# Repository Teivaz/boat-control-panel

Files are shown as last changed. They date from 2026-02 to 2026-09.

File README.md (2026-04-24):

# Panel 01

Electrical control panel for a boat. A single three-board unit that drives the
cabin relays, exposes them through a button panel with per-button RGB
feedback, and displays system state (battery, fuel and fresh-water level,
sensors, clock, nav-light selection) on a small OLED.

## Hardware layout

Three PIC18F27Q84 boards communicate over a shared I2C bus (multi-master):

| Board | Directory | Role |
|---|---|---|
| Switching | `circuit/board1-switching/` | 16 relay outputs (shift-register + mux back-read), 2 float-meter inputs, battery divider, 3 digital sensors (bilge / shore / AC). |
| Button (L/R) | `circuit/board2-buttons/` | 7 momentary buttons with per-button RGB indicator LEDs and configurable trigger modes. Two physical boards per unit (left and right), address selected by strap. |
| Main | `circuit/board3-main/` | SSD1322 OLED, DS3231 RTC, config switch. Orchestrates the other boards: receives button events, maintains relay intent, drives nav-light logic, and hosts the config menu. |

## Repository layout

- `firmware/` — C firmware for all three boards. Self-contained build via
  Docker (`firmware/build.sh`). See [`firmware/CLAUDE.md`](firmware/CLAUDE.md)
  and [`firmware/protocol.md`](firmware/protocol.md) for the I2C protocol,
  module conventions, and per-board details.
- `circuit/` — KiCad schematics and PCB layouts, one directory per board plus
  a shared symbol/footprint library (`panel-library.*`) and connection
  diagrams.
- `design/` — Front-panel artwork (Affinity Designer / Photo sources) and DXF
  exports for panel cutouts.
- `models/` — STEP files for mechanical assemblies and 3D-printed parts.
- `playground/` — Experimental sketches (currently the SSD1322 I2C display
  bring-up).

## Functional overview

- **Power**: a panel-wide power button on the left board gates every
  non-nav-light relay. Relay and nav-mode state are restored from a RAM
  snapshot when power is toggled back on.
- **Relays (5..15)**: instruments, autopilot, inverter, water pump, fridge,
  deck/cabin lights, USB, two aux channels. Each is tied to a single button
  and toggles on press. A button flags ERROR when the physical relay state
  doesn't converge to the requested one.
- **Nav lights (relays 0..4)**: anchoring / tricolor / steaming / bow / stern
  driven by a 3-button nav-mode selector. The main board filters requested
  combinations against the configured "enabled lights" mask (set in the
  config menu) and surfaces an error if the request is incompatible.
- **Config mode**: toggling the RA7 switch on the main board enters a menu
  (nav-light mask, time-of-day, water/fuel float offsets). The same buttons
  become menu navigation while active.
- **Button trigger modes**: each button has an independent trigger
  (release / hold / change) and time threshold, configured via the protocol
  and persisted to each board's data EEPROM.

## Firmware highlights

- No RTOS — all boards share a cooperative 1 ms-tick scheduler (`libcomm/
  task.c`) with a deferred ISR-to-main-loop queue (`run_in_main_loop`).
- Transport-agnostic protocol library (`libcomm/`) linked into all three
  boards. I2C, buttons, relays, NVM, and display code are board-local.
- Built with Microchip XC8 v3.10 inside a pinned Docker image; no MPLAB X
  install required. `./firmware/build.sh` from a board source directory
  produces a `.hex` in `dist/default/production/`.
- No unit tests — validation is done on hardware via a PICkit/ICD
  programmer. Per-board readmes in `firmware/board{1,3}/readme.md` document
  pinout and wiring.

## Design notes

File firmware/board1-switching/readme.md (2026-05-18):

#Board 1. Switching

This board contains 16 relay channels, each is controlled and monitored.

## Communication

RC3 SCK
RC4 SDA

## Relay controls

The relays are controlled with 2 shift registers MC74HC595A connected in series.

The "Address" column is the bit position in the 16-bit shift word, with bit 0
the lowest bit (transmitted last, lands at the near-end shift-register output).

| Protocol Bit | Address | Channel Name |
|---|---|---|
| 0 | 1 | main |
| 1 | 0 | instruments |
| 2 | 2 | autopilot |
| 3 | 3 | bow_light |
| 4 | 4 | stern_light |
| 5 | 5 | steaming_light |
| 6 | 6 | anchor_light |
| 7 | 8 | tricolor_light |
| 8 | 11 | inverter |
| 9 | 9 | fresh_water_pump |
| 10 | 10 | fridge |
| 11 | 14 | deck_lights |
| 12 | 7 | cabin_lights |
| 13 | 15 | usb |
| 14 | 12 | aux1 |
| 15 | 13 | aux2 |

### Pinout

RA0 A
RA1 LATCH_CLK
RA2 SHIFT_CLK
RB1 nRST

The nOUT_EN is connected to GND.

## Relay channel monitoring

The relay channel output is monitored via 2 multiplexer/demultiplexer SN74LV4051A connected in parallel.
Logical 1 on the input means the channel has power.

| Bit | Multiplexer | Channel Name |
|---|---|---|
| 5 | 0 | main |
| 2 | 1 | instruments |
| 7 | 0 | autopilot |
| 6 | 0 | bow_light |
| 4 | 0 | stern_light |
| 3 | 0 | steaming_light |
| 0 | 0 | anchor_light |
| 1 | 0 | tricolor_light |
| 7 | 1 | inverter |
| 2 | 0 | fresh_water_pump |
| 5 | 1 | fridge |
| 3 | 1 | deck_lights |
| 1 | 1 | cabin_lights |
| 0 | 1 | usb |
| 6 | 1 | aux1 |
| 4 | 1 | aux2 |

The addressing of the multiplexer is done with A B and C pins, simultaneous for both multiplexers. Reading done through COM pin. The nINH is connected to GND.

### Pinout

RB3 0A 1A
RB4 0B 1B
RB5 0C 1C
RA3 0COM
RA4 1COM

## Level sensors

The fresh water tank and fuel tank levels are measured by voltage on corresponding pins. The voltage is generated by current source and is correlated lineary with the resistance of the floats. Float can function in 0-190 Ω or 240–33 Ω. Current source is fixed at 5mA. The resistance of the wire should be taken into account when converting voltage to tank level (an offset value stored in EEPROM config).

Battery voltage is divided by 10 and sent to ADC input on the controller. Battery is a 12V acid. The voltage can be correlated with its charge via formula or lookup table.

### Pinout

RA7 Fuel tank level
RA5 Fresh water tank level
RA6 Battery voltage

## Other sensors

Additionally the chip is monitoring 3 on/off channels. High or low level on the pins indicates channel state.

RC1 Bilge float triggered
RC2 Shore power present
RC5 AC power present

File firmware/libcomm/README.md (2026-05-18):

# libcomm — Shared I2C Protocol Library

Shared library for multi-board I2C communication on PIC18F27/47/57Q84.

## Components

| File | Description |
|---|---|
| `i2c.h` / `i2c.c` | Async, interrupt-driven I2C multi-master driver (host + client) |
| `libcomm.h` / `libcomm.c` | Protocol message builders, parsers, and type definitions |
| `libcomm_interface.h` / `libcomm_interface.c` | High-level send/dispatch layer over I2C + libcomm |
| `task.h` / `task.c` | Cooperative task scheduler with ISR-safe deferred callbacks |

## I2C Driver (`i2c.h`)

Interrupt-driven I2C host + client driver on I2C1.  Default 100 kHz (400 kHz
when `I2C_FME=1`), 7-bit addressing, multi-master with automatic collision
retry.  Bus timeout uses the peripheral BTO (LFINTOSC).

No pin setup, no ISR definitions — boards provide pin/PPS in `i2c_board.c`;
ISRs are defined internally in `i2c.c`.

### API

```c
void i2c_init(uint8_t client_addr);     /* 0 = host-only                */
void i2c_set_cold_rx_handler(I2cCompletion); /* cold-rx delivery (main) */
I2cResult i2c_set_client_tx(uint8_t* tx, uint8_t tx_len); /* stage read reply */
I2cResult i2c_submit(addr, tx, tx_len, rx_len, cb, ctx);
void i2c_poll(void);                     /* main loop — fires callbacks  */
```

ISR-level functions (`I2C1_ISR`, `I2C1_ERROR_ISR`) are defined internally
in `i2c.c` — boards do not need to wire them manually.

### How it works

```
    Main loop                       ISR context
    ─────────                       ───────────

  i2c_submit() ──────┐
                     ▼
              ┌────────────┐
              │ Pending Q  │  ring buffer, 16 slots
              │ [0] [1]... │  each with 8-byte TX buffer
              └─────┬──────┘
                    │  i2c_poll()
                    ▼
              ┌────────────┐
              │ Active op  │  owns the I2C bus
              │ byte-level │  ISR shifts TX/RX per byte
              └─────┬──────┘
                    │  I2C1_ISR()     sets status flags
                    │  (BTO timeout)  enforces timeout
                    ▼
              ┌────────────┐
              │ Completed  │  i2c_poll() fires callback
              └────────────┘  and starts next queued op
```

### Context separation

| Function | Context | Notes |
|---|---|---|
| `i2c_init` | Main | Call once before super-loop |
| `i2c_set_cold_rx_handler` | Main | Set cold-rx delivery handler |
| `i2c_set_client_tx` | Main | Stage client read-reply buffer |
| `i2c_submit` | Main | Copies tx into queue, returns immediately |
| `i2c_poll` | Main | Fires callbacks, starts next op |

ISRs (`I2C1_ISR`, `I2C1_ERROR_ISR`) are internal to `i2c.c`.
No function is called from both contexts.

### Configuration

Override before including `i2c.h`:

| Define | Default | Description |
|---|---|---|
| `I2C_QUEUE_SIZE` | 16 | Queue depth (must be power of 2) |
| `I2C_TX_MAX` | 8 | Max bytes per TX payload |
| `I2C_RX_MAX` | 8 | Max bytes per RX payload |
| `I2C_CLIENT_BUF_SIZE` | 8 | Max inbound message size (client mode) |
| `I2C_RETRY_COUNT` | 1 | Retry count on bus collision / timeout |

### Board integration

```c
// In main.c:
i2c_pins_init();                  // board-specific pin setup (i2c_board.c)
i2c_init(comm_address());         // 0 = host-only
comm_interface_init();            // registers protocol dispatchers

// Main loop:
while (1) {
    i2c_poll();
    task_controller_poll(&ctrl);
}
```

ISRs are defined inside `libcomm/i2c.c` — boards do not need to provide them.

## Protocol Interface (`libcomm_interface.h`)

High-level layer that connects the I2C driver with the protocol
builders/parsers.  Provides:

1. **Send functions** — `comm_send_*()` for every protocol command
2. **Dispatchers** — automatically parse incoming I2C messages and
   call typed adopter callbacks
3. **Adopter callbacks** — board implements `comm_on_*()` for the
   commands it handles; empty stubs for the rest

### Outbound

```c
// Write commands (fire-and-forget):
comm_send_button_changed(button_id, pressed, mode, cb, ctx); // → main board
comm_send_relay_state(relays, cb, ctx);                       // → switching board
comm_send_button_effect(addr, &effect, cb, ctx);              // → button board

// Read commands (async response via callback):
comm_send_battery_read();     // response → comm_on_battery_read_response()
comm_send_config_read(addr, config_addr);
```

### Inbound (adopter implements)

```c
// Main-loop context — incoming writes:
void comm_on_button_changed_received(const CommButtonChanged* event);
void comm_on_channel_changed_received(const CommChannelChanged* event);
void comm_on_reset(void);

// Main-loop context — read responses:
void comm_on_battery_read_response(CommBattery* battery);

// ISR context — incoming read requests:
void comm_on_config_read_requested(uint8_t address);
```

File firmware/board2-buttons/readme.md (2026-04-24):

# The Board 2. Buttons

This board holds up to 8 buttons with corresponding RGB LEDs for feedback.

The buttons are connected to a port directly and on press shorten the pin to GND.
The RGB LEDs are connected in series from 0 to 7. With 7 not installed.

## Pinout

RA5 Button 0
RA4 Button 1
RA3 Button 2
RA2 Button 3
RA1 Button 4
RA0 Button 5
RA6 Button 6
RA7 Button 7 (not connected)

RC2 RGB LED

RC3 SCL
RC4 SDA

RB0 L/R
RB1 Reserved

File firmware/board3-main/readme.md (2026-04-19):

# Board 3. Main

The main board keeps track of all internal states, it receives messages from other boards (e.g. buttons) or polls (~200ms) boards (e.g. RTC). This board also is equipped with 64x256 display where in the normal mode it only shows 3 items: level of fresh water, level of fuel, charge of the battery (acid 12V battery, measured by voltage). This board controls navigational lights (bow, stern, steaming, anchoring, tricolor).

## Communications

RB1 SDA
RB2 SCL

Other
RA7 CONFIG_MODE (changes the main board mode into configuration disabling normal functionality)

## Navigational lights

The board also shows the state of each navigational light. This state corresponds to the state of the corresponding channel on the switching board.
The lights are connected in the followign order:

- Anchoring
- Tricolor
- Steaming
- Bow
- Stern

The lights operate in following modes:

- Off
- Anchoring. Combination of anchoring or steaming+stern.
- Steaming. Combination of stern+bow+steaming or bow+anchoring.
- Running. Combintation of stern+bow or just tricolor.

In the config mode any light can be disabled. The system then should find a way to implement the required light pattern using available lights. If not possible it should flash red to indicate error.

The leds used LTST-E563C.

### Pinout

RB5 LED (series of 5)

## Buttons

Communication with buttons is done throught I2C specified in protocol.md.

Left button panel has buttons connected in following order:

- Power. Toggles the functionality of the whole pannel. When off none of the relays are activated.
- Instruments. Controls instruments relay.
- Autopilot. Controls autopilot relay.
- Steaming lights. Enables Steaming mode of navigational lights. When mode is already active it switches the mode to Off. Contols some of the navigational lights relays.
- Runnning lights. Enables Running mode of navigational lights. When mode is already active it switches the mode to Off. Contols some of the navigational lights relays.
- Anchoring lights. Enables Anchoring mode of navigational lights. When mode is already active it switches the mode to Off. Contols some of the navigational lights relays.
- Inverter. Controls inverter relay.

Left button panel has buttons connected in following order:

- Fresh water pump.
- Fridge.
- Deck lights.
- Cabin lights.
- USB outlets.
- Aux 1.
- Aux 2.

The button once pressed should be put into pulsating mode, then trigger corresponding channel on the switching board. Once the channel status on the switching board is set the button effect should be changed to enabled.
If the button state is not changed after 100ms the channel state should be changed to error, which should be displayed as red flashing light. Toggling the button again should clear error state and turn the channel off.

## Relays

Communication with relays is done throught I2C specified in protocol.md.

## Display

The display is SSD1322 OLED monochrome display 64x256 operating in 8080 mode. nCS connected permanently to GND, EnRD pulled up.

The graphics library u8g2, the parts of the library that are used need to be copied to the source folder.

### Pinout

RB0 DnC
RB3 nRST
RB4 RnW
RC0 D0
RC1 D1
RC2 D2
RC3 D3
RC4 D4
RC5 D5
RC6 D6
RC7 D7

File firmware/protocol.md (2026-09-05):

# I2C Communication Protocol Description

All devices should be able to operate in standard (100 kHz) and fast (400 kHz) modes.
The system operates in multi-master mode with an event-based system. If a device needs to implement polling the time interval for polling calls should be ≥ 20 ms.
Addressing scheme is 7-bit.
Signal lines are pulled up to 3.3V.

## Addresses

0x40 - Main control board
0x41 - reserved
0x42 - Switching board
0x43 - reserved
0x44 - button board L
0x45 - button board L2
0x46 - button board R
0x47 - button board R2
0x48..0x4F - reserved
0x68 - RTC module (DS3231)

## Messages

All write messages begin with a command byte (byte 0) with the MSB clear (0x00–0x7F). Read messages use a write phase to send the command byte with the MSB set (0x80–0xFF), followed by a repeated-start read phase. The read command ID equals the write command ID OR 0x80.

### Checksum

Every on-wire message ends with a single CRC-8 byte (polynomial `0x07`, initial value `0x00`, no final XOR — the SMBus/SAE-J1850 CRC). The CRC is computed over every preceding byte of that message:

- **Write messages** (id + payload): CRC spans `[id, payload[0..N-1]]`. Total wire length is `1 + N + 1` bytes.
- **Read-phase responses** (payload only, no id): CRC spans `[payload[0..N-1]]`. Total wire length is `N + 1` bytes.
- **Command-only messages** (`reset`, most `*_read` write phases): CRC spans `[id]` alone. Total wire length is 2 bytes.

Receivers drop any message whose trailing byte doesn't match the computed CRC. Per-byte payload sizes below do **not** include the CRC byte; add 1 to the byte count on the wire.

| Command | Value | Direction |
| --- | --- | --- |
| `reset` | 0x0F | main → any (write) |
| `config` | 0x0E | main → any (write) |
| `config_read` | 0x8E | main → any (read) |
| `button_effect` | 0x01 | main → button board |
| `button_changed` | 0x02 | button board → main |
| `button_state_read` | 0x83 | main → button board (read) |
| `button_trigger` | 0x04 | main → button board (write) |
| `button_trigger_read` | 0x84 | main → button board (read) |
| `relay_state` | 0x05 | main → switching board (write) |
| `relay_state_read` | 0x85 | main → switching board (read) |
| `channel_changed` | 0x06 | switching board → main |
| `channel_state_read` | 0x87 | main → switching board (read) |
| `battery_read` | 0x88 | main → switching board (read) |
| `levels_read` | 0x89 | main → switching board (read) |
| `level_mode` | 0x0A | main → switching board (write) |
| `level_mode_read` | 0x8A | main → switching board (read) |
| `sensors_read` | 0x8B | main → switching board (read) |
| `test_echo` | 0x0C | any → any (write) |
| `test_echo_response` | 0x0D | any → requester (write) |
| `test_read` | 0x8C | any → any (read) |

### Common

The following commands are supported by every addressable device.

- reset - perform a soft reset; the device restarts as if powered on. No response is emitted.
  - write byte 0: command - 0x0F

- config - write one byte of the device configuration. Persisted to non-volatile storage; survives power cycles. Address space and byte meaning are device-specific.
  - write byte 0: command - 0x0E
  - write byte 1: address - byte offset within the device configuration
  - write byte 2: value - configuration byte to store

- config_read - read one byte of the device configuration
  - write byte 0: command - 0x8E
  - write byte 1: address - byte offset within the device configuration
  - read byte 0: value - configuration byte at the requested address

The low end of the configuration address space is reserved for universal fields present on every device. Device-specific fields live at `0x10` and above.

| Address | Field | Access | Description |
|---|---|---|---|
| 0x00 | device_id | read-only | 7-bit I2C address of this device; matches the address used to reach it |
| 0x01 | hw_revision | read-only | Hardware revision, monotonic per board |
| 0x02 | sw_revision | read-only | Firmware revision, monotonic per build |

#### Diagnostic test commands

Bus-bring-up / integration-test helpers. Every device services them with no application involvement.

- test_echo - the requester writes its own address and an arbitrary value; the receiver replies with a `test_echo_response` write addressed to that requester, carrying the responder's own address and the same value. The `address` field always identifies the sender, so the requester learns which device answered. Exercises the multi-master write path in both directions (requester and receiver must each act as host).
  - write byte 0: command - 0x0C
  - write byte 1: address - requester's own I2C address (where the response is sent)
  - write byte 2: value - arbitrary value, echoed back unchanged

- test_echo_response - the reply emitted by a device that received a `test_echo`.
  - write byte 0: command - 0x0D
  - write byte 1: address - responder's own I2C address
  - write byte 2: value - the value from the test_echo, unchanged

- test_read - the write phase carries one value byte; the read phase returns that same byte. Exercises the client-TX read-staging path with a single host (no second master needed).
  - write byte 0: command - 0x8C
  - write byte 1: value - arbitrary value to be echoed
  - read byte 0: value - the value from the write phase, unchanged

### Main board (0x40)

- button_changed - pushed by a button board when a button's trigger fires, or when its trigger is (re)configured
  - write byte 0: command - 0x02
  - write byte 1: device_address - address of the sending button board
  - write byte 2: button_id - `[7:6]` = 0, `[5:4]` = button mode, `[3]` button pressed, `[2:0]` button index

- channel_changed - pushed by the switching board when any channel-voltage bit (mux-observed downstream of each relay's fuse) or any sensor changes state
  - write byte 0: command - 0x06
  - write byte 1: device_address - address of the sending switching board
  - write byte 2: prev_channels_lo - previous channel-voltage state of channels 0–7; bit N = channel N
  - write byte 3: prev_channels_hi - previous channel-voltage state of channels 8–15; bit N = channel N−8
  - write byte 4: current_channels_lo - current channel-voltage state of channels 0–7
  - write byte 5: current_channels_hi - current channel-voltage state of channels 8–15
  - write byte 6: prev_sensors - previous sensor state; `[7:3]` = 0, `[2]` sensor_2, `[1]` sensor_1, `[0]` sensor_0
  - write byte 7: current_sensors - current sensor state; same layout as prev_sensors

### Button board (0x44–0x47)

The input register is 1 byte representing the physical state of 8 buttons (bit N = button N; 1 = pressed, 0 = released). The trigger mode determines when a `button_changed` is emitted per button, but the register value always reflects the raw button state.

Each button has an independent mode and timing configured via `button_trigger`:

| Mode | Bits | Behaviour |
|---|---|---|
| `unknown` | `00` | No trigger configured; no events fire. Default on power-on. |
| `release` | `01` | Event fires when the button is released after being held for ≥ the configured time. No event if released early. |
| `hold` | `10` | Event fires once when the button has been held for ≥ the configured time. |
| `change`  | `11` | Event fires on every button state change. No time parameter. |

- button_effect - set the visual effect for each of the 8 button outputs
  - write byte 0: command - 0x01
  - write byte 1: outputs_76 - upper nibble = output 7, lower nibble = output 6
  - write byte 2: outputs_54 - upper nibble = output 5, lower nibble = output 4
  - write byte 3: outputs_32 - upper nibble = output 3, lower nibble = output 2
  - write byte 4: outputs_10 - upper nibble = output 1, lower nibble = output 0

  Each nibble encodes one output as `CC MM` — `[3:2]` color, `[1:0]` mode.

  | CC | Color |
  |---|---|
  | 00 | white |
  | 01 | red |
  | 10 | green |
  | 11 | blue |

  | MM | Mode |
  |---|---|
  | 00 | disabled |
  | 01 | enabled |
  | 10 | flashing (fast) |
  | 11 | pulsating (slow) |

- button_state_read - polled read; returns the current physical state of all buttons
  - write byte 0: command - 0x83
  - read byte 0: current_state - current value of the input register

- button_trigger - write the trigger configuration for a single button
  - write byte 0: command - 0x04
  - write byte 1: `[7:3]` = 0, `[2:0]` button_id
  - write byte 2: `MM EE TTTT` — mode and timing for the button

  Default value on power-on is `0x00` (`unknown`, no events).

  **Time encoding:** `t = TTTT × 10^EE ms`. TTTT=0 means immediate (t=0ms).

  | EE | Resolution | Range |
  |---|---|---|
  | 0 | 1 ms | 1–15 ms |
  | 1 | 10 ms | 10–150 ms |
  | 2 | 100 ms | 100–1500 ms |
  | 3 | 1000 ms | 1–15 s |

- button_trigger_read - read the trigger configuration for a single button
  - write byte 0: command - 0x84
  - write byte 1: `[7:3]` = 0, `[2:0]` button_id
  - read byte 0: `MM EE TTTT` for the requested button

### Switching board (0x42)

The switching board has 16 relay channels. Each channel has three observable states:

- **relay target** — what the firmware was last commanded to set (`relay_state` write).
- **channel voltage** — the voltage observed downstream of the relay's fuse, read via the relay-output mux. A blown fuse can leave a relay commanded ON while its channel reads 0; a stuck contactor can do the inverse.

Both states are 2-byte bitmasks transmitted low byte first: byte 0 = bits 0–7, byte 1 = bits 8–15 (bit N = channel N; 1 = on, 0 = off).

- relay_state - write the target state of all 16 relays
  - write byte 0: command - 0x05
  - write byte 1: relays_lo - target state of relays 0–7
  - write byte 2: relays_hi - target state of relays 8–15

- relay_state_read - read the commanded target state of all 16 relays (the last value written via `relay_state`)
  - write byte 0: command - 0x85
  - read byte 0: relays_lo
  - read byte 1: relays_hi

- channel_state_read - read the channel-voltage state of all 16 channels (mux-observed; reflects fuse / contactor health, not just the commanded relay target)
  - write byte 0: command - 0x87
  - read byte 0: channels_lo
  - read byte 1: channels_hi

- battery_read - polled read; returns battery voltage as an unsigned 16-bit value
  - write byte 0: command - 0x88
  - read byte 0: voltage_lo - low byte
  - read byte 1: voltage_hi - high byte

- levels_read - polled read; returns both level meter values in a single message
  - write byte 0: command - 0x89
  - read byte 0: level_0 - unsigned 8-bit value of level meter 0
  - read byte 1: level_1 - unsigned 8-bit value of level meter 1

- level_mode - write the operating mode of both level meters
  - write byte 0: command - 0x0A
  - write byte 1: `[7:4]` = 0, `[3:2]` mode_1, `[1:0]` mode_0

  Mode values (matching `CommMeterMode` in `libcomm.h` — the wire encoding is
  the enum value, so these must stay in lockstep):

  | Value | Name | Meaning |
  |---|---|---|
  | `00` | `COMM_METER_MODE_CALIBRATION` | Raw Ω passthrough — the reported byte is the calibrated resistance, not a percentage. Selected via the main board's config menu (water/fuel mode items) so the operator can watch the sender's actual resistance while picking the matching `water_cal` / `fuel_cal` byte. |
  | `01` | `COMM_METER_MODE_0_190` | European, 0–190 Ω; full = high resistance. **Default.** |
  | `10` | `COMM_METER_MODE_240_33` | American, 240–33 Ω; full = low resistance. |
  | `11` | — | Reserved. |

  A resistance more than 1.5× beyond the mode's high-resistance end (>360 Ω in
  `0b10`, >285 Ω in `0b01`) is reported as the over-range sentinel 255 — float
  disconnected or sender rail open — which the main board renders as an error
  rather than a level. In `COMM_METER_MODE_CALIBRATION` there is no sentinel:
  the byte is the raw Ω value clamped to 255, so 255 there means "≥255 Ω".

- level_mode_read - read the operating mode of both level meters
  - write byte 0: command - 0x8A
  - read byte 0: `[7:4]` = 0, `[3:2]` mode_1, `[1:0]` mode_0

- sensors_read - polled read; returns the state of all 3 on/off sensors
  - write byte 0: command - 0x8B
  - read byte 0: `[7:3]` = 0, `[2]` sensor_2, `[1]` sensor_1, `[0]` sensor_0 — 1 = on, 0 = off

## Configuration

Configuration is per-device byte-addressable storage backed by data EEPROM. `config` writes are persisted across power cycles; `config_read` returns the in-RAM shadow that mirrors EEPROM. A byte that has never been written reads back as 0xFF (the EEPROM erase pattern); accessors with a sensible fallback substitute the per-field default listed below.

Universal addresses 0x00..0x0F are documented in [Common](#common). Device-specific fields:

### Main board configuration (0x40)

| Address | Field | Size | Default | Description |
|---|---|---|---|---|
| 0x10 | nav_enabled_mask | 1 | 0x1F | 5-bit mask of physically-installed nav lights — `[0]` anchoring, `[1]` tricolor, `[2]` steaming, `[3]` bow, `[4]` stern. Limits which lights the panel attempts to drive when a nav-mode button is pressed; cleared bits are silently skipped and a mode that requires a missing light raises a config error on the indicator. |
| 0x11 | indicator_brightness | 1 | 0x10 | Peak per-channel intensity (0..255) for the nav-indicator RGB ring. Re-read each frame so a runtime change takes effect within ~50 ms. Kept in lockstep with the button board's `led_brightness` so the panel reads uniformly. |

### Button board configuration (0x44–0x47)

| Address | Field | Size | Default | Description |
|---|---|---|---|---|
| 0x10..0x16 | button_trigger[7] | 7 | hold trigger | One CommTriggerConfig (MMEETTTT) per button — same wire format as `button_trigger` command payload. Default mode is `hold` with a 1 ms time on most buttons; the L-board's button 0 defaults to 800 ms. |
| 0x17..0x1A | button_effect | 4 | disabled / white | Four packed CommButtonEffect bytes (two outputs per byte; upper nibble = odd output, lower nibble = even output) — same wire format as `button_effect` command payload. Default colour is white, mode disabled (LEDs dark). |
| 0x1B | led_brightness | 1 | 0x10 | Peak per-channel intensity (0..255) for the per-button RGB LEDs. Applied uniformly across R/G/B so hue is preserved; re-read each frame. Kept in lockstep with the main board's `indicator_brightness` so the panel reads uniformly. |

### Switching board configuration (0x42)

| Address | Field | Size | Default | Description |
|---|---|---|---|---|
| 0x10 | water_cal | 1 | 100 | Water-level scale factor — byte the channel reports with a 100 Ω reference applied. The ADC processor inverts the factor when displaying Ω so a tolerance-shifted current source / divider just changes this byte. |
| 0x11 | fuel_cal | 1 | 100 | Fuel-level scale factor — same calibration semantics as `water_cal`. |
| 0x12 | battery_cal | 1 | 120 | Battery scale factor — byte the channel reports at a 12000 mV reference, in 100 mV units. |
| 0x13 | level_mode | 1 | 0x05 | Packed CommLevelMode — `[3:2]` mode_1, `[1:0]` mode_0; same layout as `level_mode` command payload. Persists meter mode across reboot. Default 0x05 = both meters in 0–190 Ω mode (`COMM_METER_MODE_0_190` in both fields). |

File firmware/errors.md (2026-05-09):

# Compilation Warnings Audit

Snapshot of XC8 v3.10 and clang diagnostics across `board1-switching`,
`board2-buttons`, `board3-main` as of 2026-04-24. All three boards build
clean (no errors). Warnings are grouped by mechanism; each entry lists the
root cause and whether action is warranted.

## 1. Non-reentrant duplication for `run_in_main_loop` (resolved)

```
task.c:120: advisory (2098) indirect function call via a NULL pointer ignored
task.c:120: warning  (759)  expression generates no code
task.c:100..102: advisory (1498) pointer (run_in_main_loop@c) may have no targets
```

These warnings applied when no board called `run_in_main_loop`. Since then,
`board2-buttons/input.c:62` calls `run_in_main_loop(ctrl, dispatch_pending, 0)`
from its IOC ISR to defer button debounce into main context. With a live
caller the pointer analysis resolves and the dispatcher is emitted. These
warnings should no longer appear for board2-buttons builds.

## 2. Dead code in board modules (520 — never called)

Functions declared and defined in board-local modules with no caller in the
linked image. Linker drops them from the final hex; cost is source clutter.

### board3-main/controller.c
- `controller_power_on` (211)
- `controller_nav_mode` (214)
- `controller_relay_target` (220)
- `controller_sensors` (232)

Four getters that were likely intended for `comm.c` to serve read requests
but aren't wired. `board3-main/comm.c` has no callers for them.

### board2-buttons
- `config.c:131` `config_set_button` — wrapper over `config_write_byte`.
  The dispatcher in `comm.c:100` calls `button_set_trigger` directly
  instead, which internally persists.
- `config.c:146` `config_set_effect` — same pattern; dispatcher calls
  `led_effect_set` directly (`comm.c:156`).
- `led_effect.c:35` `led_effect_get` — no reader of current effect state.

**Action**: either delete the dead wrappers or route the dispatcher through
them (would consolidate persistence into `config.c`). Low priority.

## 3. Unused libcomm API per board (520)

`libcomm/libcomm.c` exports builders and parsers for every command in the
protocol. Each board links all of them but only calls a subset:

| Board | Unused command families (sample) |
|---|---|
| board1-switching | all button\_\* builders/parsers, button\_effect\_\*, config builders, relay\_mask\_\*, relay\_changed, reset, sensors\_read |
| board2-buttons | relay\_\*, battery, levels, level\_mode, sensors, config builders |
| board3-main | build\_button\_changed, button\_trigger\_\*, most read-side builders |

**Impact**: none — XC8 linker discards unreferenced symbols.

**Action**: none. This is inherent to sharing one library across
heterogeneous devices. Could be eliminated with per-board `-D` guards
around optional builders, but the added conditional compilation costs more
than the dead code.

## 4. Non-reentrant duplication (1510)

```
... non-reentrant function "_X" appears in multiple call graphs
    and has been duplicated by the compiler
```

Affected across all boards: any module whose API is reachable from both
main and ISR contexts — `config_read_byte`, `config_write_byte`,
`queue_lookup`, `eeprom_offset_for`, `nvm_read`, `i2c_*`, `sensors_state`,
`button_set_trigger`, `button_index`, `led_effect_set`, `input_state_current`,
`task_controller_add`, `task_controller_remove`, `find_slot`, `comm_address`,
and the XC8 runtime helpers (`__awdiv`, `__lwdiv`, `__lwmod`).

**Cause**: XC8's 8-bit model disallows reentrancy by default — locals sit
in fixed allocation banks rather than on a stack. When the same function
is reached from two call graphs (ISR + main), XC8 duplicates the code so
each context has its own locals. This is correct and is the mechanism that
makes our ISR-callable annotations safe.

**Impact**: modest code-size hit (one extra copy per duplicated function).
Already accounted for in the 7.8% / 10.0% program-space usage reported by
the build.

**Action**: none. Confirms the ISR-callable annotations accurately reflect
reality. If code space ever gets tight, candidates for ISR→defer rework
would reduce duplication.

## 5. Function-pointer targets unresolved (1498 advisory)

```
advisory: (1498) pointer (<fn>@<param>) in expression may have no targets
```

Fires for every libcomm builder/parser taking `CommMessage*` or typed
output pointers. XC8 cannot resolve the targets because the callers pass
`&local` from a different translation unit.

**Impact**: none — pure static-analysis limitation. The calls are
resolvable by ordinary C semantics at link time.

**Action**: none.

## 6. u8g2 vendor warnings (board3-main only)

Two groups, both from the vendored `u8g2/` subtree:

- **clang sign-conversion / int-conversion** (~100 hits across
  `u8g2_arc.c`, `u8g2_font.c`, `u8g2_polygon.c`, `u8g2_selection_list.c`,
  `u8g2_ll_hvline.c`, `u8g2_kerning.c`, `u8g2_message.c`,
  `u8g2_input_value.c`, `u8x8_cad.c`). Upstream style; not our code.
- **XC8 (1481) "call from non-reentrant function … to `_byte_cb` might
  corrupt parameters"** on the u8x8 display-driver dispatch pointers.
  `_byte_cb` is u8g2's callback registered from a single context, but XC8
  sees it reachable from multiple drivers and cannot prove reentrancy
  safety.

**Impact**: vendor code runs only from main context in our use, so the
(1481) parameter-corruption warning is spurious for our call pattern. The
clang sign warnings are cosmetic.

**Action**: none. Touching `u8g2/` would diverge from upstream.

## 7. Summary

- 1 resolved concern (§1) — `run_in_main_loop` now has a live caller in
  board2-buttons; warnings should no longer appear for that board.
- 7 locally dead functions (§2) — candidates for cleanup in a follow-up.
- Everything else (§3–§6) is structural: consequence of a shared library
  over heterogeneous devices, the XC8 non-reentrancy model, or vendor code.

Build output captured with `../build.sh` from each board directory after
`make clean CONF=default`.

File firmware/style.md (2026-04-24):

# Firmware style & consistency notes

Derived from a file-by-file audit of `board1-switching/` and `board2-buttons/`. These are the conventions the board already follows (and which `.clang-format` does not by itself capture), followed by the inconsistencies found during the audit and the fixes applied.

## Conventions in use

### Module layout
- One `foo.h` / `foo.c` pair per responsibility (`adc`, `i2c`, `relay_out`, `relay_mon`, `sensors`, `controller`, `config`, `comm`, `interrupt`).
- `foo_init(...)` is always the first exported symbol. Modules that schedule periodic work take `TaskController* ctrl` so the caller owns the scheduler; modules with no timed work take no argument (`adc_init`, `i2c_init`, `relay_out_init`, `relay_mon_init`, `comm_init`).
- Header comments describe *what the unit owns and how to call it*, not line-by-line behavior.

### Naming
- Exported functions: `module_verb[_noun]` (`relay_out_write`, `adc_read_battery_mv`, `controller_set_relay_target`, `sensors_state`).
- File-static helpers: verb-first, no module prefix (`apply_target`, `start_burst`, `handle_event`, `flush_task`, `ioc_handler`).
- Scheduled callbacks end in `_task` (`monitor_task`, `retry_task`, `flush_task`, `poll_task`).
- Task IDs live in each board's `task_ids.h` as an anonymous `enum`, `TASK_*` prefix.
- Pin/register aliases use `PIN_*` or `SEL_*` / `COM_*` macros (`PIN_NRST`, `SEL_A`, `PIN_BILGE`).
- Compile-time constants: `SCREAMING_SNAKE_CASE` with a module-specific prefix (`ADC_FVR_MV`, `SENSORS_POLL_MS`, `WRITE_QUEUE_SIZE`).

### Types & argument style
- `uint8_t` is the default integer. `uint16_t` for relay masks and raw ADC counts, `uint32_t` only where required (EMA accumulators).
- Pointer declarations use `Type* name` (matches `.clang-format`'s `PointerAlignment: Left`).
- Every no-arg function is declared as `func(void)` — including ISRs.
- Buffer parameters always come as `(const uint8_t* data, uint8_t len)` pairs; response buffers as `(uint8_t* response, uint8_t response_max)` with the return value being the number of bytes written.
- Status enums (`I2cResult`) are returned; scheduler-style functions return `int8_t` with documented negative codes.
- Bitfield struct fields keep the LSB-first layout that matches the wire format — never reorder.

### Concurrency discipline
- **Main context**: `main()`, `task_controller_poll`, every `*_task` callback.
- **ISR context**: each peripheral ISR (`I2C1_ISR`, `AD_ISR`, `IOC_ISR`, `TMR0_ISR`) plus the `on_rx` / `on_read` handlers that `i2c.c` invokes from its ISR. Every ISR-callable function carries an `ISR context` / `ISR-callable` comment.
- Any variable shared between the two is `volatile`. Multi-byte volatile reads/writes from main context wrap access in `INTERRUPT_PUSH` / `INTERRUPT_POP` (from `libcomm.h`). Pure-ISR shared variables don't need the guard because ISRs don't preempt each other here.
- ISR context → main context handoff uses a `push_dirty` flag plus a periodic task that drains the state; handlers invoked from an ISR (`on_rx`, `on_read`, change callbacks) must stay short and avoid blocking peripherals.

### Interrupts
- All vectors use `__interrupt(irq(NAME), base(8))` with the IVT locked at `0x0008` by `interrupt_init`.
- Each ISR is defined in the module that owns the peripheral it serves (`TMR0_ISR` in `main.c`, `IOC_ISR` in the input/sensors module that enables IOC, `I2C1_ISR` in `i2c.c`, `AD_ISR` in `adc.c`). The peripheral-specific interrupt enablement (`PIE*`, `IPR*`, and the peripheral's `IE`/`IP` bits) lives alongside the ISR in the same module.
- `interrupt.c` holds only `interrupt_init` (IVT lock/unlock + `GIE`) plus `__asm("RESET")` stubs for vectors that no module claims. No function-pointer dispatch table.

### Comments
- Top-of-file comment: what the module owns, how the hardware is wired, and any non-obvious invariants (e.g. the wire-bit ↔ protocol-bit mapping tables, EMA time constant rationale).
- Inline: only where the *why* is not obvious (register magic numbers, timing assumptions, mid-flight glitch handling).
- No running narration of what the next line does.

## Findings and fixes

### Fixed
1. **`controller_level` parameter name drift**
   Header declared `controller_level(uint8_t meter_index)` but the definition used `uint8_t i`. Renamed to `meter_index` to match.

2. **Dead accessor `controller_relay_physical`**
   Declared in `controller.h` and defined in `controller.c`, never called. `relay_physical` is still used internally by `monitor_task` / `retry_task`; only the unused getter and its declaration were removed.

3. **Stray-vector ISR signatures**
   `interrupt.c` declared every reset-trap ISR with an empty `()` argument list (e.g. `SWINT_ISR()`), while the two real handlers in the same file (`IOC_ISR(void)`, `TMR0_ISR(void)`) used `(void)`. All reset-trap ISRs now use `(void)` for consistency.

4. **Module-private state marked `extern`**
   `interrupt_handler_IOC` and `interrupt_handler_TMR0` were file-scope non-`static`, exposing them as global symbols even though only `interrupt.c` uses them. Marked `static`.

### Accepted as-is
- **`comm.c` `COMM_LEVEL_MODE` handling** skips `comm_parse_level_mode_write` and passes `data[1]` directly to `controller_set_level_mode`, which masks with `0x0F`. The parser itself just does the same `& 0x0F`, so the net effect is identical and routing a 1-byte bitfield through a parser-and-cast would be noisier than the current line. If more fields are added to `CommLevelMode` later, switch to the parser.
- **`adc_read_level_fresh_water` / `adc_read_level_fuel` duplication**. Two near-identical one-liners; per the "reuse after the third copy" rule this is still acceptable. Revisit if a third level meter appears.
- **clangd false positives** (`task.h`/`xc.h` not found, `GIE` undeclared). The Makefile supplies `-I../libcomm` and the XC8 DFP path at build time; standalone clangd doesn't see them. Not a source issue.

## For new code in this repo

- Mirror the `_init(TaskController*)` + `_task` pattern for anything that needs periodic work — don't add a second scheduling mechanism.
- Keep I2C-command dispatch in `comm.c`; keep transport (`i2c.c`) free of libcomm types.
- When a handler has to move data from ISR to main context, use a `volatile` shadow + dirty flag drained by a task — not a callback that blocks in the ISR.
- Wire a fresh IRQ by adding the `__interrupt(irq(...), base(8))` definition in the module that owns the peripheral and deleting the matching reset-trap stub in `interrupt.c`. Enable the interrupt (`PIE*`, `IPR*`) in the same module.

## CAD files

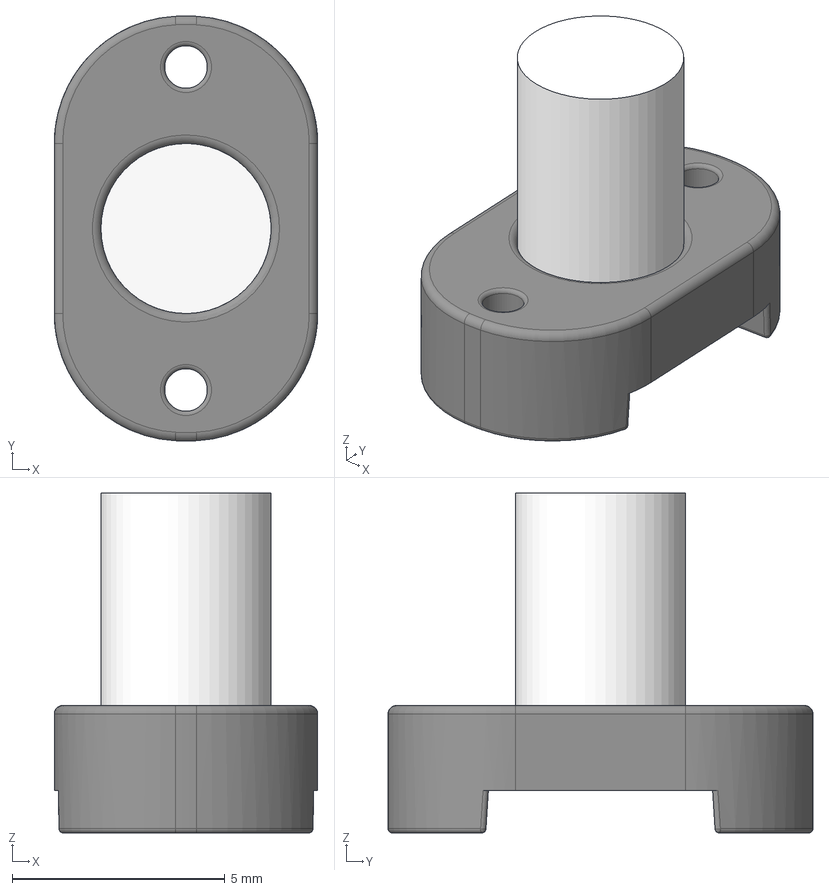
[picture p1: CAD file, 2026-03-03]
circuit/3dmodels/Ledpipe-5x5.step
6.20 x 10.00 x 8.00 mm

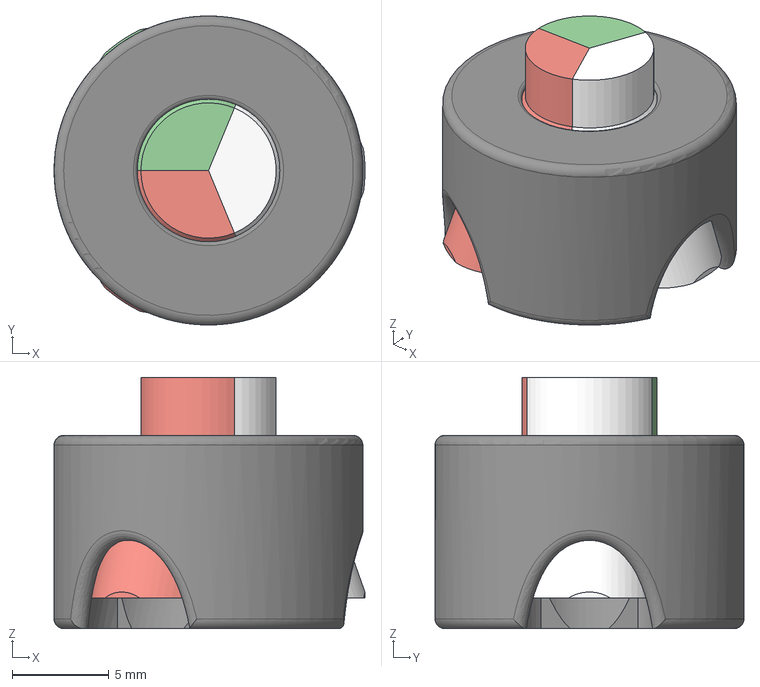
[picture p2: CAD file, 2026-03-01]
circuit/3dmodels/ledpipe_3p.step
16.1 x 16.0 x 13.0 mm

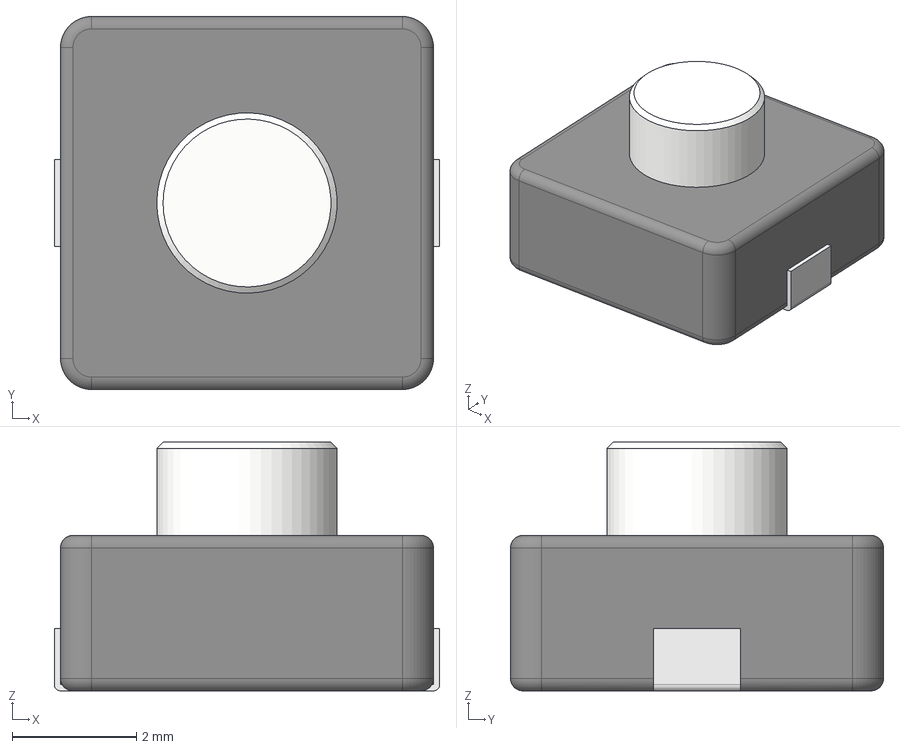
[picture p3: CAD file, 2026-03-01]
circuit/3dmodels/Button-EVPCD.step
6.20 x 6.00 x 4.00 mm

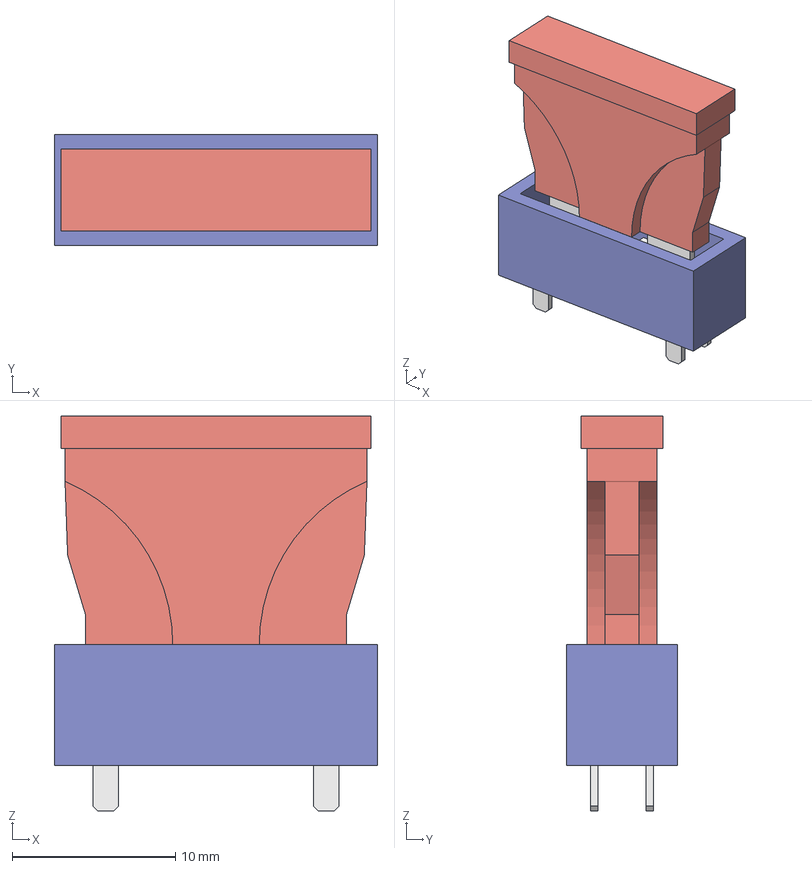
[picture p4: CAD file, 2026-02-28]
circuit/3dmodels/BladeFuseHolder.step
19.8 x 6.80 x 24.2 mm
BladeFuseHolder
BladeFuse

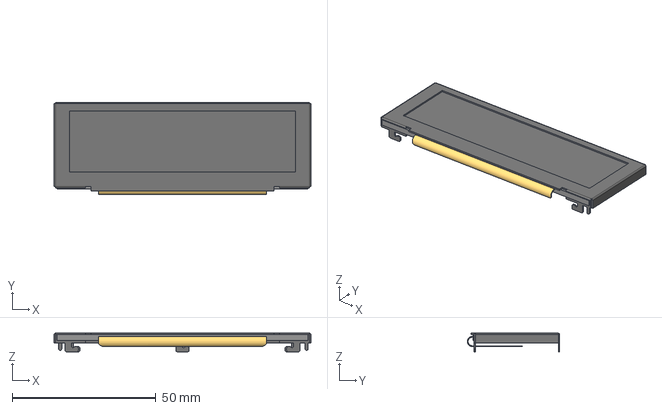
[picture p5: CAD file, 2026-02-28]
circuit/3dmodels/Display_OLED_3.12in.step
89.5 x 32.2 x 6.50 mm
Display_3.12in
Display_3.12in_frame

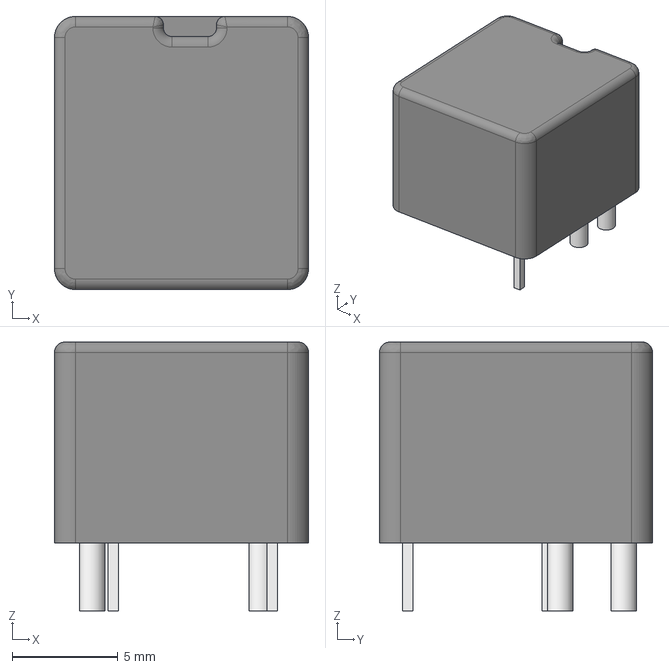
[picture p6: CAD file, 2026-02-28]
circuit/3dmodels/Relay-TE-V23086-C1xxx.step
12.0 x 12.9 x 12.7 mm

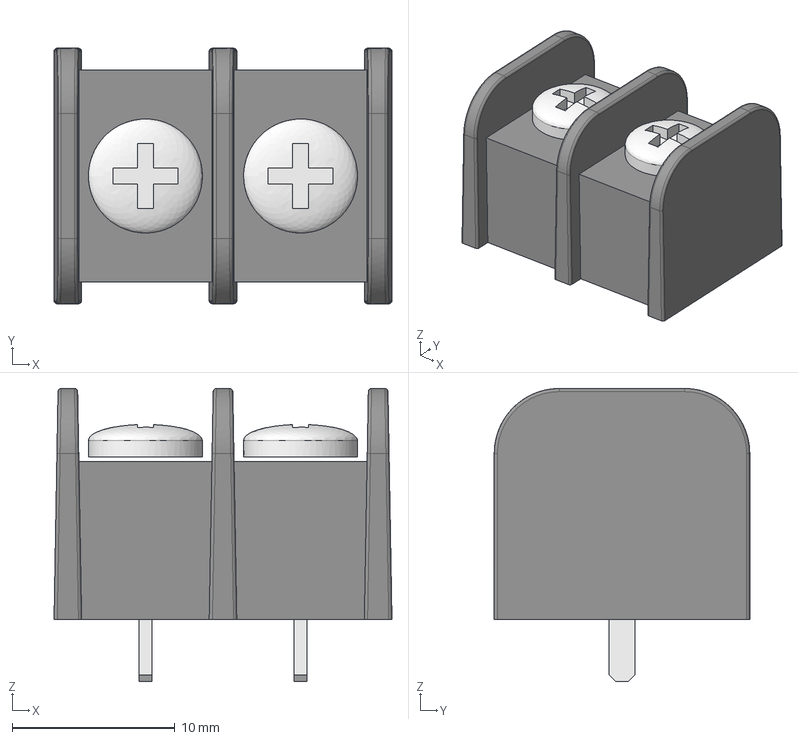
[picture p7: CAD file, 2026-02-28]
circuit/3dmodels/Con-Molex-38710-6302.step
20.8 x 15.7 x 18.0 mm

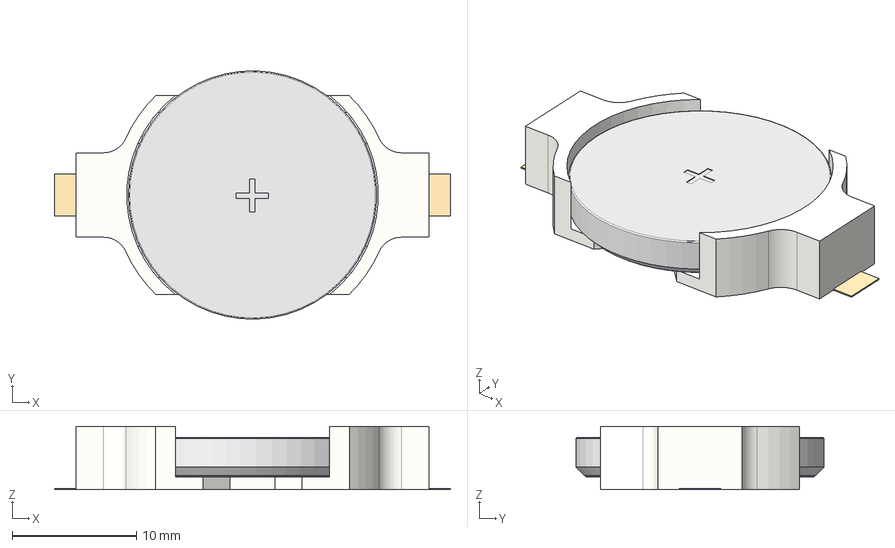
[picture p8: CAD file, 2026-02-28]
circuit/3dmodels/CR2032-Keystone-1058.step
31.9 x 20.0 x 5.08 mm
CR2032-Keystone-1058
CR2032

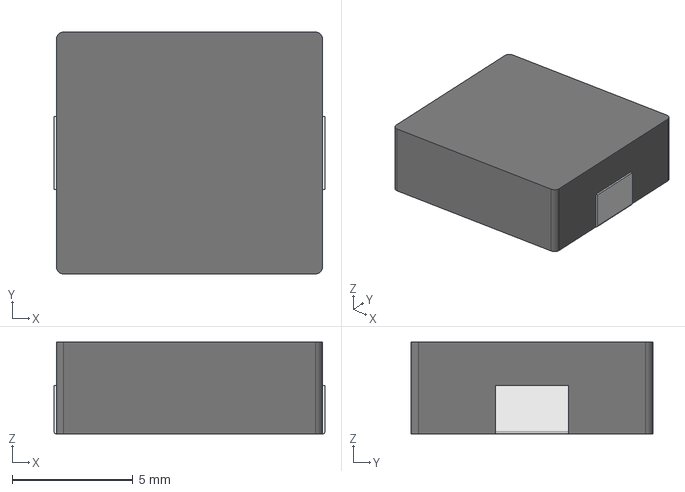
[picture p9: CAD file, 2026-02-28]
circuit/3dmodels/L_Abracon_AMDLA1004S.step
11.2 x 10.0 x 3.80 mm

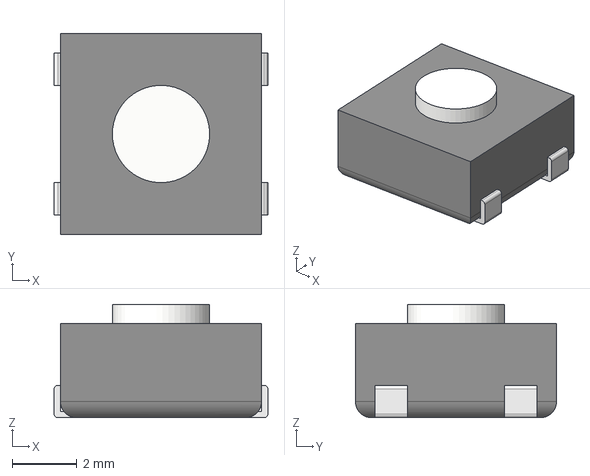
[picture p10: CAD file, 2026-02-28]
circuit/3dmodels/ButtonSMT_CnK_KSC2_J.step
6.60 x 6.20 x 3.50 mm

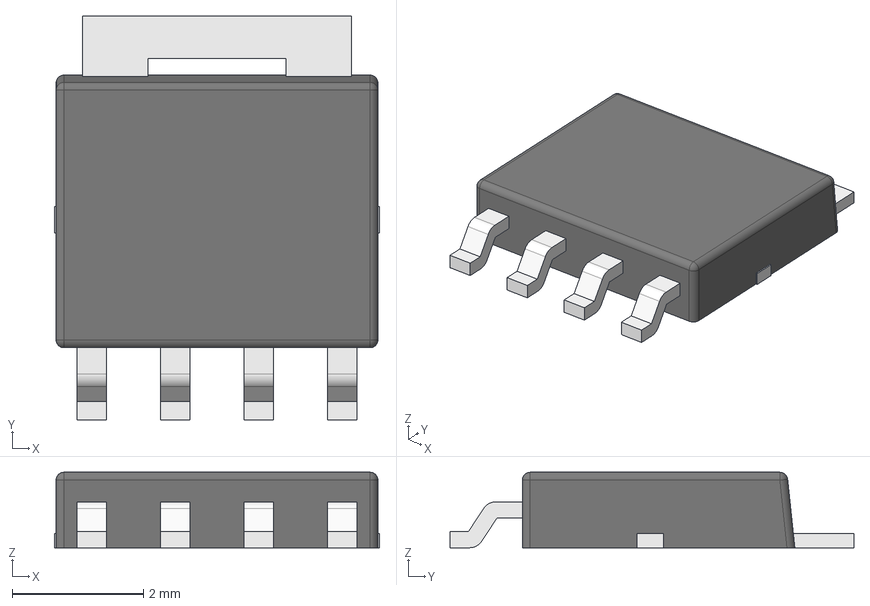
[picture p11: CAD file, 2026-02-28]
circuit/3dmodels/LFPAK4.step
4.95 x 6.15 x 1.15 mm

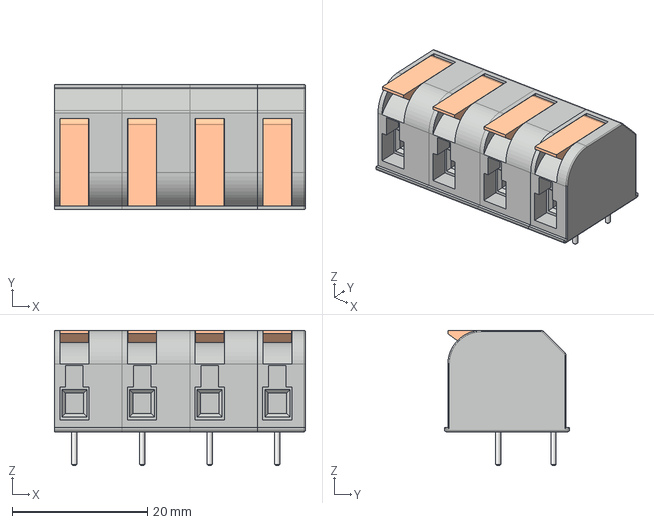
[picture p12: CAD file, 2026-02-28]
circuit/3dmodels/Con-Amphenol-QT04CDP.step
37.1 x 18.5 x 20.0 mm
Con-Amphenol-QT0xCDP-Unit x 3
Con-Amphenol-QT0xCDP-LastUnit

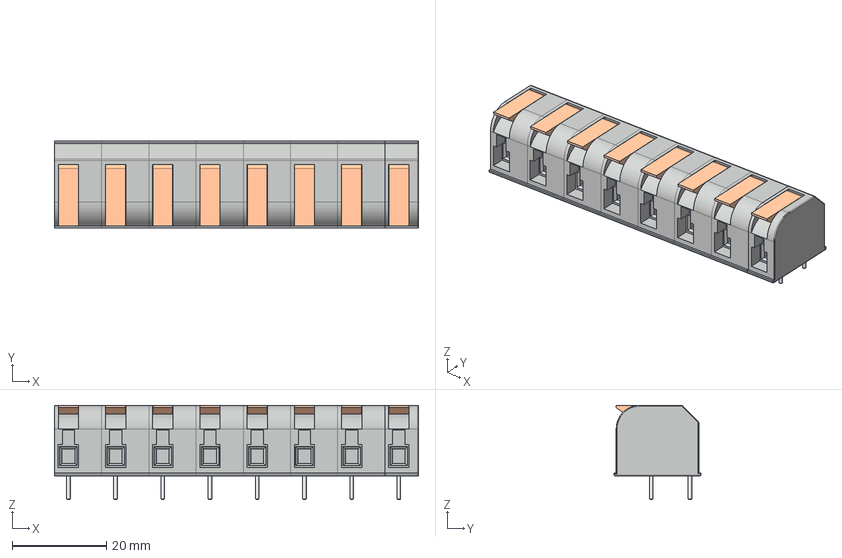
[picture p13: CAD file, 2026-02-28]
circuit/3dmodels/Con-Amphenol-QT08CDP.step
77.1 x 18.5 x 20.0 mm
Con-Amphenol-QT0xCDP-Unit x 7
Con-Amphenol-QT0xCDP-LastUnit

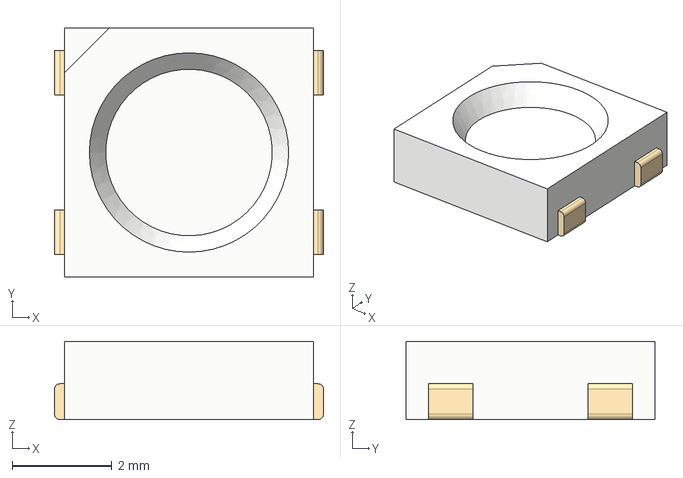
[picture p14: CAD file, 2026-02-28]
circuit/3dmodels/LTST-E563CHEGBW.step
5.40 x 5.00 x 1.57 mm

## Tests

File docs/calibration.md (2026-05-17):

# Calibration

Procedures for bringing a freshly-flashed switching board into agreement
with its sensors. Each calibration writes a single byte into the
switching board's EEPROM via the inspector CLI, so the values survive a
reboot.

The three calibrations (water level, fuel level, battery voltage) are
independent — pick whichever needs adjustment, in any order. None of
them depend on the others.

## Prerequisites

- Switching board flashed with current firmware.
- Main board powered (so the I2C bus has its pull-ups energised), or
  external pull-ups in place. The inspector talks to the switching board
  directly; the main board doesn't have to be doing anything.
- CH347 USB-to-I2C dongle wired to the switching board's I2C lines:
  RC3 → SDA, RC4 → SCL, GND common.
- `tools/inspector/inspector` built (`make` from that directory; depends
  on `libusb-1.0`).
- The float harness for the channel being calibrated **disconnected**
  during the bench reference steps; reconnect after.

## Workflow at a glance

1. (Optional) Confirm fresh defaults survived flashing:
   ```
   inspector sw config read 0x10        # water cal — should be 100
   inspector sw config read 0x11        # fuel cal  — should be 100
   inspector sw config read 0x12        # battery cal — should be 120
   inspector sw config read 0x13        # level mode — should be 0x05
   ```
2. Calibrate the level meters (sections below). Order between water/fuel
   doesn't matter.
3. Calibrate the battery.
4. Reconnect the harnesses.

If any of step 1's reads return values that aren't the defaults above,
the EEPROM was written previously — calibrate from scratch and overwrite,
or `config read` each before starting if you want to preserve them.

## Level meters (water, fuel)

Each level channel has one calibration byte:

| Channel | Protocol address |
| --- | --- |
| Water | `0x10` (`CONFIG_ADDR_WATER_CAL`) |
| Fuel  | `0x11` (`CONFIG_ADDR_FUEL_CAL`) |

The byte is the displayed Ω that the channel produced when a 100 Ω
reference was applied. Default is `100` (no correction). The firmware
multiplies by `100 / cal_byte`, so a 100 Ω input always reads 100 Ω
regardless of harness resistance and current-source tolerance.

### Procedure

1. **Switch both meters to calibration mode (raw-Ω passthrough):**

   ```
   inspector sw meter write 0 0
   ```

   In this mode the `levels` byte for each channel is the calibrated Ω
   directly, clamped to `0..255`. Sloshing-compensation EMA is still
   applied, so allow ~30 s for each reading to settle.

2. **Open the inspector in repeat mode** so the reading refreshes
   live:

   ```
   inspector -r 1000 sw levels
   ```

3. **Zero check** — short the channel's input to GND. The reading must
   converge to 0. If it sits non-zero (anything > a count or two), there's
   a hardware fault upstream of the firmware (current-source ground
   reference, harness short, or ADC offset) — the new calibration model
   has no offset knob to compensate, so resolve the hardware issue
   before continuing.

4. **Span measurement** — apply a precision (1% or better) 100 Ω
   reference resistor between the channel input and GND. After ~30 s,
   note the displayed value `V`. If the hardware is within spec, expect
   `V` somewhere in the 95..105 range.

5. **Write the calibration byte** using the value you just read:

   ```
   inspector sw config write 0x10 <V>     # water  (use 0x11 for fuel)
   ```

   `<V>` is the literal number you noted in step 4 (decimal `97` or hex
   `0x61` — both work). The next conversion frame (~1 ms) picks up the
   new byte; the EMA then washes in over ~30 s.

6. **Verify** — keep the 100 Ω reference applied. After ~30 s the
   reading should sit at 100 Ω ±1. If it's off by more than that, the
   value you read in step 4 hadn't fully settled — re-read it and
   re-write step 5.

7. **Swap to the other channel** and repeat steps 3–6.

8. **Switch both meters back to the operating mode:**

   ```
   inspector sw meter write 1 1     # European 0..190 Ω (default)
   # or
   inspector sw meter write 2 2     # American 240..33 Ω
   ```

   The mode is persisted to EEPROM (`CONFIG_ADDR_LEVEL_MODE = 0x13`),
   so subsequent reboots start in the chosen scale.

9. **Reconnect the float harness.**

### Mode reference

| Value | Name | Meaning |
| --- | --- | --- |
| `0` | `COMM_METER_MODE_CALIBRATION` | Raw-Ω passthrough, byte clamped to 0..255 |
| `1` | `COMM_METER_MODE_0_190` | European; full = 190 Ω, empty = 0 Ω. **Default** |
| `2` | `COMM_METER_MODE_240_33` | American; full = 33 Ω, empty = 240 Ω |

`meter write <m0> <m1>` — `m0` is water, `m1` is fuel; both expressed
in the values above.

### Verifying

```
inspector sw config read 0x10        # water cal byte
inspector sw config read 0x11        # fuel cal byte
inspector sw config read 0x13        # packed level mode (low nibble = mode_1<<2 | mode_0)
inspector sw meter read              # decoded mode for both channels
```

## Battery

Same shape as the levels — one byte storing what the channel reported
when a known reference was applied. The reference is **12 000 mV**.
Because the reading is 16 bits but the cal byte is 8, the byte is in
**100 mV units**: write `round(displayed_mV / 100)`, default `120`.
The firmware then computes `corrected_mV = raw_mV × 120 / cal_byte`.

A first-order EMA with τ ≈ 400 ms is applied — fast enough to track
real load sag from a starter or inverter while smoothing alternator and
switching-transient noise.

| Field | Address | Default | Meaning |
| --- | --- | --- | --- |
| Battery cal | `0x12` (`CONFIG_ADDR_BATTERY_CAL`) | 120 | `round(displayed_mV / 100)` at 12 000 mV reference |

### Procedure

1. **Apply a 12.000 V reference** to the battery input. Either:
   - A bench supply trimmed against a calibrated DMM, or
   - A known-charged battery measured with the DMM, used in place of
     the boat battery.

   The accuracy of your reference is the floor on calibration accuracy.
   100 mV at 12 V is ~0.83%, so any DMM ≤ 0.5% is fine.

2. **Watch the live reading** — give it ~2 s after each connection for
   the EMA to settle:

   ```
   inspector -r 1000 sw voltage
   ```

3. **Compute the byte** as `round(displayed_mV / 100)`. Examples:

   | Displayed mV | Byte (decimal / hex) |
   | --- | --- |
   | 11 800 | 118 / `0x76` |
   | 11 850 | 119 / `0x77` (rounded up from 118.5) |
   | 12 000 | 120 / `0x78` (default) |
   | 12 200 | 122 / `0x7A` |

4. **Write the byte:**

   ```
   inspector sw config write 0x12 <byte>
   ```

5. **Verify** — keep the 12 V reference applied. After ~2 s the reading
   should sit at 12 000 mV ±50 mV (half of the 100 mV cal step).

Granularity is one cal step ≈ 100 mV (~0.83% on 12 V). For a state-of-
charge gauge that's fine; the divider's actual tolerance is typically
the dominant error.

### Verifying

```
inspector sw config read 0x12        # battery cal byte
inspector -r 1000 sw voltage         # live mV reading
```

## Persistence

Calibration values live in NVM EEPROM on the switching board, so they
survive a reboot or power cycle. Re-running the calibration procedure
overwrites them; flashing new firmware doesn't (unless the firmware
itself rewrites the EEPROM layout, which the firmware notes in its
release notes).

To revert to the in-firmware defaults, set each cal byte by hand:

```
inspector sw config write 0x10 100       # water cal
inspector sw config write 0x11 100       # fuel cal
inspector sw config write 0x12 120       # battery cal
inspector sw meter write 1 1             # level mode → European default
```

## Troubleshooting

**`config write` returns silently but `config read` shows the old
value.** The address you're writing isn't in `eeprom_offset_for`'s
switch — check the address against `config.h`. The protocol-level write
is delivered to the slave but `config_write_byte` drops unknown
addresses.

**Level reading still wrong after writing the cal byte.** Most common
cause: step 4's reading wasn't yet settled when you wrote it. The EMA
τ is ~6 s, so anything less than ~30 s of stability isn't reliable.
Re-read with the reference still applied, then re-write step 5.

**Battery reads ~0 mV.** With the new model and `cal=120` default,
that means the ADC isn't seeing the divider output — check the harness
to RA6 and the divider itself.

**Same value across two different meter modes.** The mode write didn't
land — the slave is probably still on a firmware older than the one
this doc assumes. Reflash and `inspector sw meter read` to confirm.

**Floating-input garbage.** With nothing connected, the channel may
read non-zero or rail-saturated. That's expected — the calibration
procedure assumes a known reference is wired in for each step.

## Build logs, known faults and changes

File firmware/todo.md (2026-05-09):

# To be fixed

- implement the timeout for main board
- make u8g2 library into static library to reduce compilation time

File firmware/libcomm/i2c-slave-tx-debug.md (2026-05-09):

# I2C Slave-TX (client-TX) DMA — open issue

Target: PIC18F27Q43, XC8 v3.10. File: `libcomm/i2c.c`.

## Symptom

A combined write+read transaction from a remote master (e.g. command `0x88` =
read with MSB set) reaches `isr_on_address` for the read phase correctly:
the slave ACKs the write address, receives the command byte via DMA into
`g_client_rx`, ACKs the restart, and ACKs the read address. After CSTR is
released, the slave fails to deliver the data bytes from `g_client_tx[]`
to the master.

What we observe on the wire varies depending on the experiment, but in the
working scenarios at most byte 0 ships correctly. Byte 1 onwards either:

- arrives as `0x00` (zeros — see "CNTIF gotcha" below), or
- causes the slave to clock-stretch via `CSD = 0` until BTO recovery fires,
  and then the master reads `0xFF` as the bus floats high.

## What works (and is using the same DMA channels)

- **Cold RX** (`i2c_dma_client_rx`): slave receives bytes from master, DMA
  drains `I2C1RXB` to `g_client_rx[]`. Reliable.
- **Host TX** (`i2c_dma_set_host`): master mode transmit driven by DMA from
  `task->tx`. Reliable.

Both use the same `DMASELECT` / `DMAnCON0` setup pattern (`EN = 0` →
`SSA/SSZ` (or `DSA/DSZ`) → `SIRQEN = 1; AIRQEN = 1; EN = 1`). So the DMA
configuration template itself is sound.

## What we changed and why (chronological)

1. **`DMAnAIRQ = 0` override restored** in `i2c_dma_init` for both TX and
   RX channels.
   The repo had drifted to leave `DMAnAIRQ = 0x3b` (I2C1E) live, which —
   combined with `AIRQEN = 1` on every arm — would abort the channel on
   any latched `NACKIF` / `BTOIF` / `BCLIF`. Unwiring the abort source
   eliminates that as a suspect.

2. **Stop programming `I2C1CNT` in `i2c_dma_client_tx`**.
   Slave-TX length is master-controlled (master decides when to NACK).
   Programming `I2C1CNTL = g_client_tx_len` made `CNTIF` fire mid-transfer
   in slave mode, which dispatches `isr_on_transmit_exhausted`.

3. **`isr_on_transmit_exhausted` `FSM_CLIENT_TX` arm now `return`s early**
   instead of dropping `CSTR`.
   Original code zeroed `g_client_tx_len` and unconditionally fell through
   to `I2C1CON0bits.CSTR = 0;`. On Q43 in slave-TX, that has the effect
   of "continue, you were stretching" — and since TXB is empty, whatever
   the SR latches happen to be (typically `0x00`) gets shifted out for as
   long as the master keeps clocking. **This is the "starts sending zeros
   when CNT exhausts" gotcha — leave the early return in place.**

4. **Made `i2c_dma_client_tx` a byte-for-byte mirror of the host-TX arm
   in `i2c_dma_set_host`** (no direct TXB write, no error-flag prelude,
   full buffer + full length, same EN cycle). Result: two `0xFF` bytes
   on the wire — the DMA never fired even once.

5. **Added `DMAnCON0bits.DGO = 1`** after `EN = 1` in
   `i2c_dma_client_tx` (current state). Theory: in slave-TX the
   peripheral is already in TX mode by the time `ADRIF` fires, so
   `I2C1TXIF` has been level-asserted with no fresh rising edge for the
   edge-triggered `SIRQEN` to catch — manual `DGO` should kick the first
   transfer. Result: **no change, still `0xFF` on the wire.** This is the
   current state and the open question.

## What this latest result tells us

- `DGO = 1` after a real `EN = 0 → 1` cycle (so `SPTR`/`SCNT` reload from
  `SSA`/`SSZ`) did not produce a transfer. That means *either*:
  - the manual-fire-via-DGO mechanism does not actually do what we think
    on this part / in this DMA mode, or
  - the DMA *did* transfer but the byte never reached `I2C1TXB` for the
    peripheral to clock out (DMA destination write somehow ignored in
    this peripheral state), or
  - the byte reached `I2C1TXB` but the peripheral didn't propagate it
    into the shift register before the master clocked the data byte.
- Either way, slave-TX byte loading via DMA is fundamentally not behaving
  like the host-TX byte loading does, despite identical channel config.

## Hypotheses ruled out

- AIRQ aborting the channel — unwired (`DMAnAIRQ = 0`).
- Stale error flags pre-arming the abort — pre-cleared in an earlier
  iteration; effect was nil.
- `I2C1CNT` driving `CNTIF` mid-transfer — no longer programmed in this
  path.
- `isr_on_transmit_exhausted` racing CSTR drop with the in-flight DMA —
  early return now in place.
- `DMAnCON0.EN` not actually transitioning 0 → 1 (so `SPTR`/`SCNT`
  wouldn't reload) — verified the cycle is in place.

## Hypotheses still open

- **Slave-TX I2C1TX SIRQ never edges.** In host-TX the `S = 1` kick puts
  the peripheral through a transmit-mode entry transition that pulses
  `I2C1TX`. In slave-TX, by the time `ADRIF` fires, the peripheral is
  already in TX mode and `TXBE` has been level-high since power-up, so
  there is nothing for `SIRQEN`'s edge detector to ride. (`DGO` should
  have been the workaround — but it didn't help, which is the puzzle.)
- **`I2C1TXB` writes from DMA might not be honored when the peripheral
  is mid-state-transition** (between ADRIF and CSTR release). If the
  peripheral only accepts TXB writes within a narrow window, the DMA
  transfer may be silently dropped.
- **The Q43 errata (DS80000870F) may apply to this path.** The init
  workaround is in place for the BTO recovery, but there may be a
  related quirk for slave-TX-after-restart that isn't documented here.

## Concrete next things to try

1. **TXIE-driven byte loading**, drop DMA for slave-TX only.
   Add an `irq(I2C1TX)` handler that writes the next byte from
   `g_client_tx[g_client_tx_idx++]` into `I2C1TXB` and disables
   `PIE7bits.I2C1TXIE` when the buffer is exhausted. Pre-load byte 0
   directly in `isr_on_address` (the direct-write path is already known
   to work for the first byte) and enable TXIE for byte 1+. This is a
   ~10-line change and matches what most reference designs do for slave-TX.

2. **Direct-write byte 0, then arm DMA for `&g_client_tx[1] / tx_len-1`,
   plus `DGO = 1`.** Combines the working byte-0 mechanism with a manual
   DMA kick. We tried direct-write+DMA without DGO (byte 0 OK, byte 1
   stretched); the DGO addition wasn't tested in *that* combination.

3. **Scope `I2C1TXIF` (or its SIRQ line) during a slave-TX read** to
   confirm/deny whether the rising edge actually happens between bytes.
   If it doesn't, DMA will never work for this path no matter what we
   try, and we have to use TXIE.

4. **Try `DMAnCON0bits.SSTP = 0`** for the TX channel as an experiment.
   Currently `SSTP = 1` (DMA stops + clears EN when SCNT hits 0). If
   something is causing SCNT to hit 0 prematurely, `SSTP = 0` would let
   it wrap and continue — useful diagnostically even if not the right
   final fix.

## Current state of `i2c_dma_client_tx`

```c
static void i2c_dma_client_tx(void) {
    if (g_client_tx_len == 0) {
        return;
    }
    INTERRUPT_PUSH;
    DMASELECT = DMA_TX_CHANNEL;
    DMAnCON0bits.EN = 0;
    DMAnSSA = (uint24_t)g_client_tx;
    DMAnSSZ = g_client_tx_len;
    DMAnCON0bits.SIRQEN = 1;
    DMAnCON0bits.AIRQEN = 1;
    DMAnCON0bits.EN = 1;
    DMAnCON0bits.DGO = 1;
    INTERRUPT_POP;
}
```

`isr_on_address` for the read path (still has the temporary `0x33`/`0x44`
test fill — see TODO in code):

```c
g_client_tx_len = 2;
g_client_tx[0] = 0x33;
g_client_tx[1] = 0x44;
if (I2C1STAT0bits.R && g_client_tx_len > 0) {
    g_fsm = FSM_CLIENT_TX;
    i2c_dma_client_tx();
    I2C1CON1bits.ACKDT = 0;
}
...
I2C1CON0bits.CSTR = 0;
```

## What was reset back to default along the way (don't redo)

- `I2C1CNT` programming in `i2c_dma_client_tx` — removed deliberately.
- `isr_on_transmit_exhausted` `FSM_CLIENT_TX` falling through to
  `CSTR = 0` — replaced with `return`.
- `DMAnAIRQ = 0` override after the `0x3b` line in `i2c_dma_init` for
  both channels — restored.

## References

- DS80000870F (PIC18F27/47/57Q43 silicon errata) — already linked in
  `i2c.c` near the BTO recovery path. Worth re-reading the slave-mode
  entries once more.
- `protocol.md` for the on-wire framing.

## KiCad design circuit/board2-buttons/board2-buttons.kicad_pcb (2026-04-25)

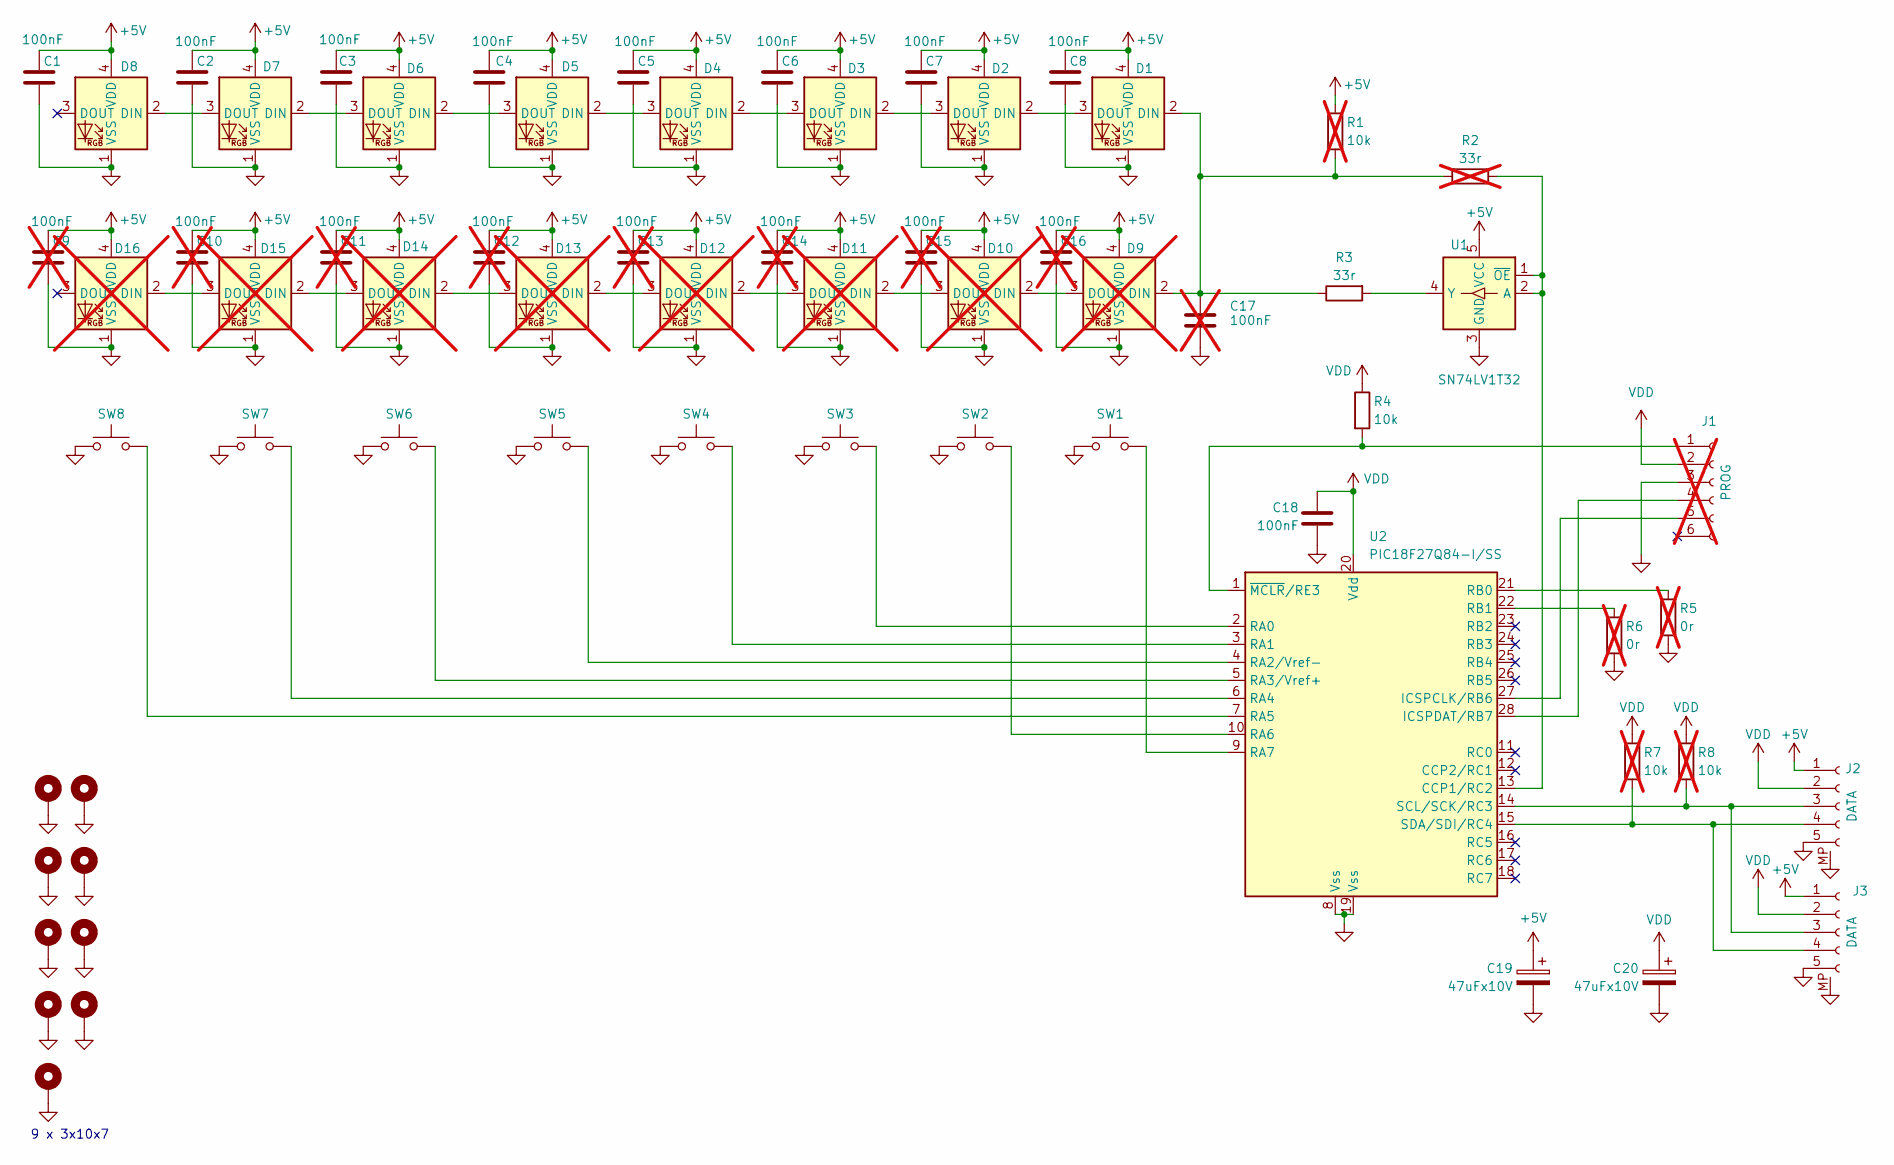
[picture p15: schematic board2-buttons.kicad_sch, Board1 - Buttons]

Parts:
C1, C2, C3, C4, C5, C6, C7, C8, C18: 100nF; C_0805_2012Metric_Pad1.18x1.45mm_HandSolder
C9, C10, C11, C12, C13, C14, C15, C16, C17: 100nF; C_0805_2012Metric_Pad1.18x1.45mm_HandSolder; not fitted
C19, C20: 47uFx10V; CP_EIA-3528-12_Kemet-T_HandSolder
D1, D2, D3, D4, D5, D6, D7, D8: LiteOn_LTST-E563C; LED_LiteOn_LTST-E563C_PLCC4_5.0x5.0mm_P3.2mm
D9, D10, D11, D12, D13, D14, D15, D16: LiteOn_LTST-E563C; LED_LiteOn_LTST-E563C_PLCC4_5.0x5.0mm_P3.2mm; not fitted
H1, H2, H3, H4, H5, H6, H7, H8, H9: 3X10X7; MountingHole_3.2mm_M3_Pad_Via_oval
J1: 1x5x2.54; PinHeader_1x06_P2.54mm_Vertical; not fitted
J2, J3: PicoLock; Molex_Pico-Lock_504050-0591_1x05-1MP_P1.50mm_Horizontal
R1, R7, R8: 10k; R_0805_2012Metric_Pad1.20x1.40mm_HandSolder; not fitted
R2: 33r; R_0805_2012Metric_Pad1.20x1.40mm_HandSolder; not fitted
R3: 33r; R_0805_2012Metric_Pad1.20x1.40mm_HandSolder
R4: 10k; R_0805_2012Metric_Pad1.20x1.40mm_HandSolder
R5, R6: 0r; R_0805_2012Metric_Pad1.20x1.40mm_HandSolder; not fitted
SW1, SW2, SW3, SW4, SW5, SW6, SW7, SW8: EVPCD; ButtonSMT_Panasonic_EVPCD
U1: SN74LV1T32; SOT-23-5
U2: PIC18F27Q84-I/SS; SSOP-28-5.3mm

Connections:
+5V: C1.1, C2.1, C3.1, C4.1, C5.1, C6.1, C7.1, C8.1, C9.1, C10.1, C11.1, C12.1, C13.1, C14.1, C15.1, C16.1, C19.1, D1.4 (VDD), D2.4 (VDD), D3.4 (VDD), D4.4 (VDD), D5.4 (VDD), D6.4 (VDD), D7.4 (VDD), D8.4 (VDD), D9.4 (VDD), D10.4 (VDD), D11.4 (VDD), D12.4 (VDD), D13.4 (VDD), D14.4 (VDD), D15.4 (VDD), D16.4 (VDD), J2.1, J3.1, R1.1, U1.5 (VCC)
GND: C1.2, C2.2, C3.2, C4.2, C5.2, C6.2, C7.2, C8.2, C9.2, C10.2, C11.2, C12.2, C13.2, C14.2, C15.2, C16.2, C17.1, C18.2, C19.2, C20.2, D1.1 (VSS), D2.1 (VSS), D3.1 (VSS), D4.1 (VSS), D5.1 (VSS), D6.1 (VSS), D7.1 (VSS), D8.1 (VSS), D9.1 (VSS), D10.1 (VSS), D11.1 (VSS), D12.1 (VSS), D13.1 (VSS), D14.1 (VSS), D15.1 (VSS), D16.1 (VSS), H1.1, H2.1, H3.1, H4.1, H5.1, H6.1, H7.1, H8.1, H9.1, J1.3, J2.5, J2.MP, J3.5, J3.MP, R5.1, R6.2, SW1.1, SW2.1, SW3.1, SW4.1, SW5.1, SW6.1, SW7.1, SW8.1, U1.3 (GND), U2.8 (Vss), U2.19 (Vss)
unnamed: C17.2, D1.2 (DIN), D9.2 (DIN), R1.2, R2.2, R3.1
unnamed: D1.3 (DOUT), D2.2 (DIN)
unnamed: D2.3 (DOUT), D3.2 (DIN)
unnamed: D3.3 (DOUT), D4.2 (DIN)
unnamed: D4.3 (DOUT), D5.2 (DIN)
unnamed: D5.3 (DOUT), D6.2 (DIN)
unnamed: D6.3 (DOUT), D7.2 (DIN)
unnamed: D7.3 (DOUT), D8.2 (DIN)
unnamed: D9.3 (DOUT), D10.2 (DIN)
unnamed: D10.3 (DOUT), D11.2 (DIN)
unnamed: D11.3 (DOUT), D12.2 (DIN)
unnamed: D12.3 (DOUT), D13.2 (DIN)
unnamed: D13.3 (DOUT), D14.2 (DIN)
unnamed: D14.3 (DOUT), D15.2 (DIN)
unnamed: D15.3 (DOUT), D16.2 (DIN)
unnamed: J1.1, R4.2, U2.1 (~MCLR/RE3)
unnamed: J1.4, U2.28 (ICSPDAT/RB7)
unnamed: J1.5, U2.27 (ICSPCLK/RB6)
unnamed: J2.3, J3.3, R8.2, U2.14 (SCL/SCK/RC3)
unnamed: J2.4, J3.4, R7.2, U2.15 (SDA/SDI/RC4)
unnamed: R2.1, U1.1 (~OE), U1.2 (A), U2.13 (CCP1/RC2)
unnamed: R3.2, U1.4 (Y)
unnamed: SW3.2, U2.2 (RA0)
unnamed: SW4.2, U2.3 (RA1)
unnamed: SW5.2, U2.4 (RA2/Vref-)
unnamed: SW6.2, U2.5 (RA3/Vref+)
unnamed: SW7.2, U2.6 (RA4)
unnamed: SW8.2, U2.7 (RA5)
unnamed: SW2.2, U2.10 (RA6)
unnamed: SW1.2, U2.9 (RA7)
unnamed: R5.2, U2.21 (RB0)
unnamed: R6.1, U2.22 (RB1)
VDD: C18.1, C20.1, J1.2, J2.2, J3.2, R4.1, R7.1, R8.1, U2.20 (Vdd)

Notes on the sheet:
9 x 3x10x7

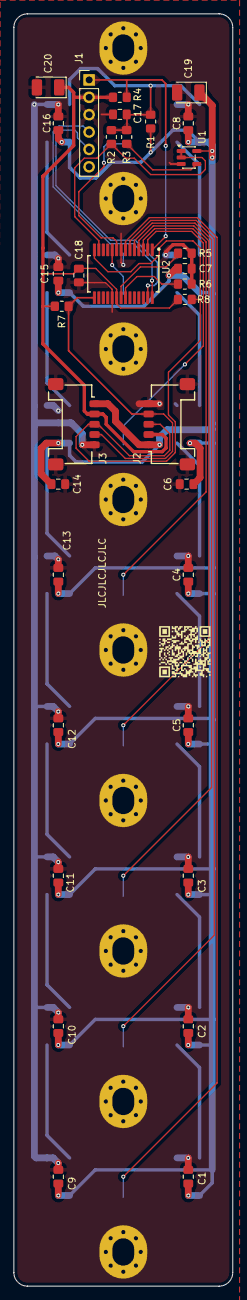
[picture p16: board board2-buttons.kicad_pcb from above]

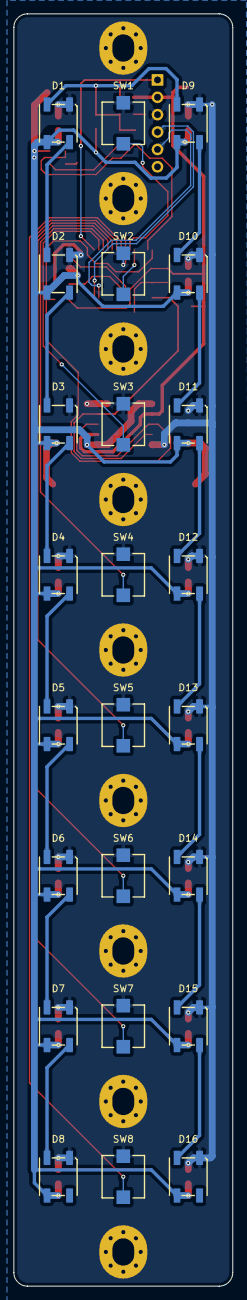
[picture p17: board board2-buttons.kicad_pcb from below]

Board: 2 copper layers, 32.0 x 186.0 mm, 66 parts (24 on the bottom side), 35 nets.

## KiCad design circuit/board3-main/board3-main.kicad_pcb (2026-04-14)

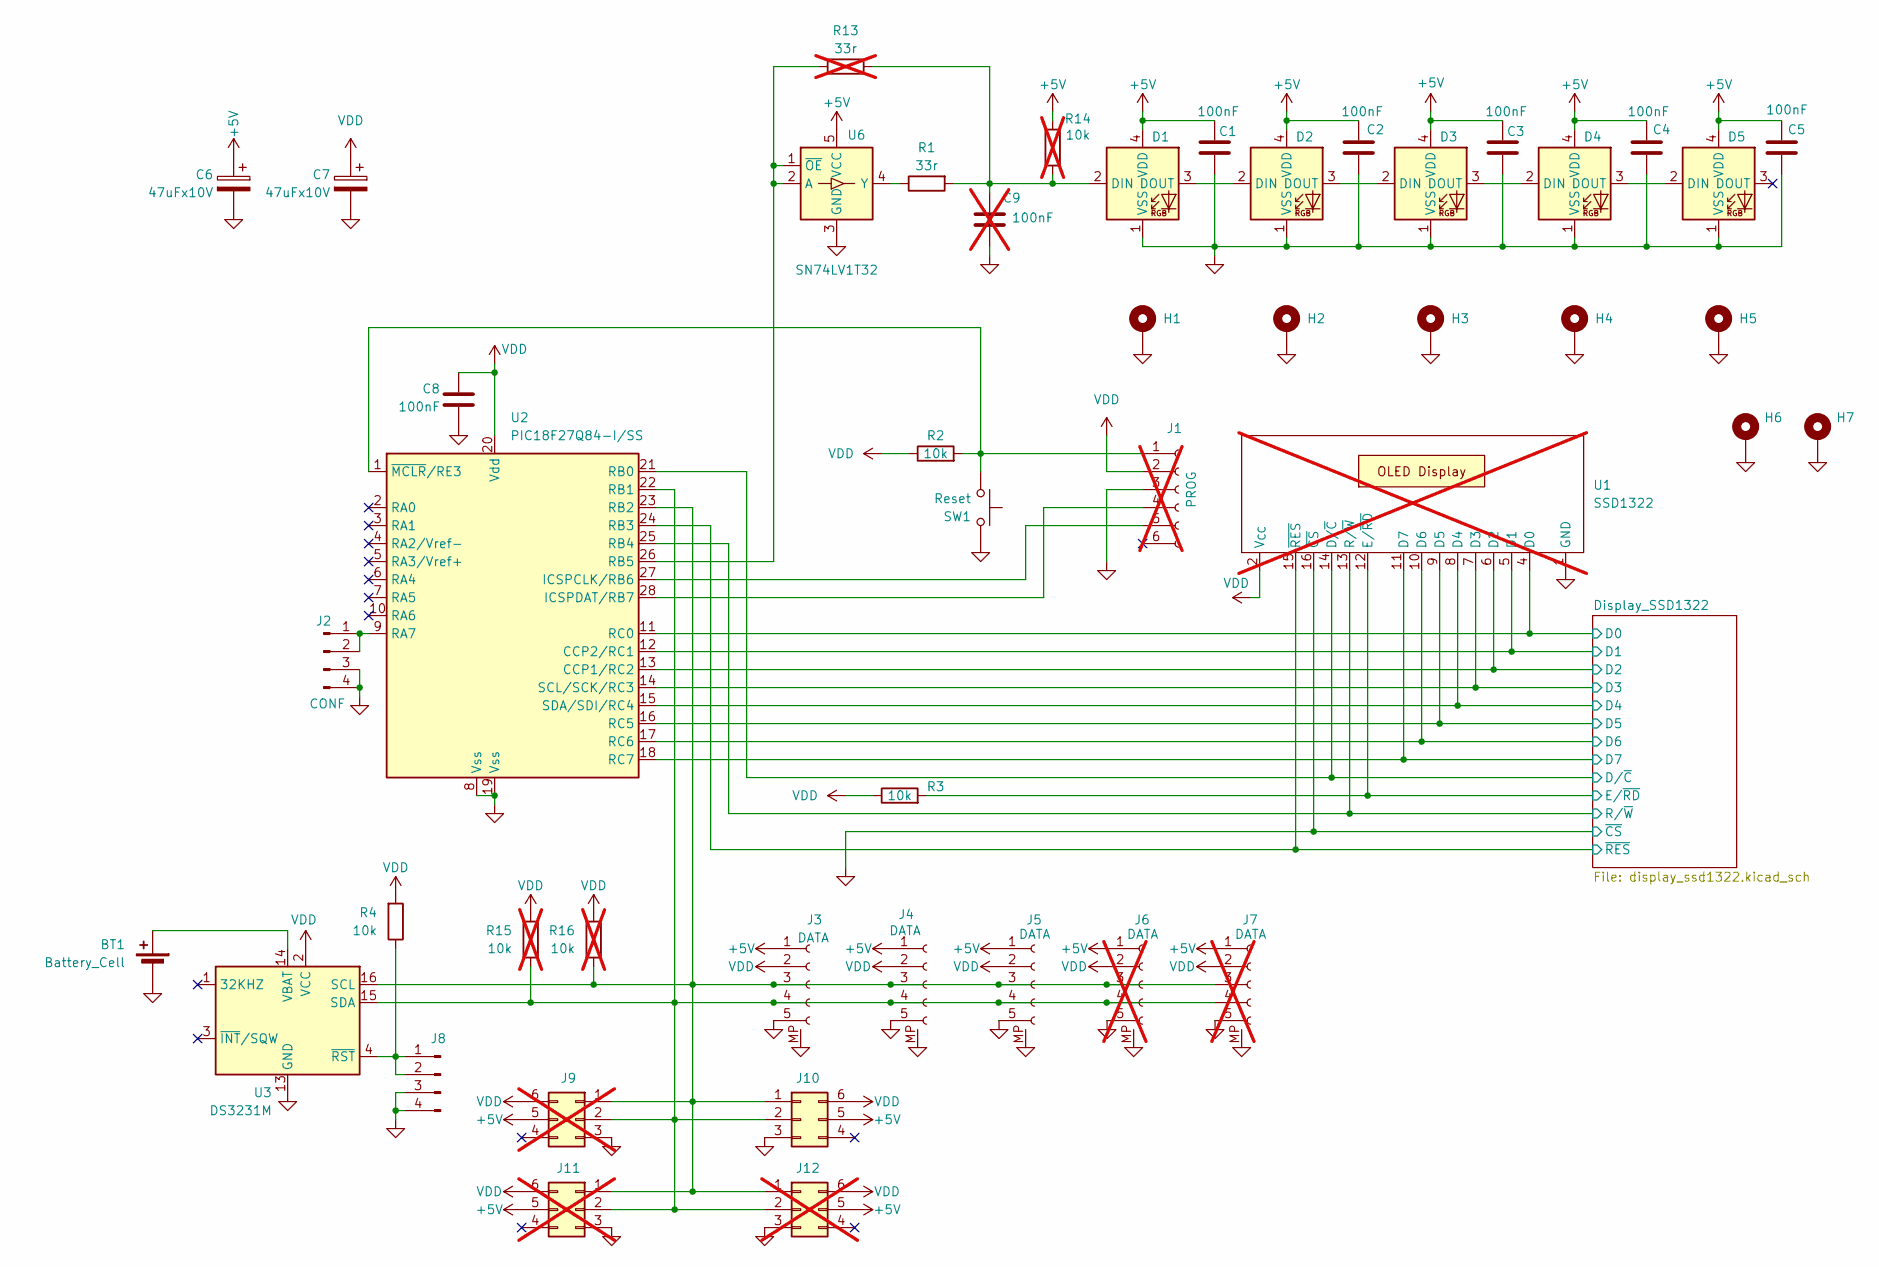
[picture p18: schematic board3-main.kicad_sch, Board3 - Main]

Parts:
BT1: Battery_Cell; Bat_Keystone_1058
C1, C2, C3, C4, C5, C8: 100nF; C_0805_2012Metric_Pad1.18x1.45mm_HandSolder
C6, C7: 47uFx10V; CP_EIA-3528-21_Kemet-B_HandSolder
C9: 100nF; C_0805_2012Metric_Pad1.18x1.45mm_HandSolder; not fitted
D1, D2, D3, D4, D5: LiteOn_LTST-E563C; LED_LiteOn_LTST-E563C_PLCC4_5.0x5.0mm_P3.2mm_MIN
H1, H2, H3, H4, H5: MountingHole_Pad; ledpipe_5x5
H6, H7: MountingHole_Pad; MountingHole_3.2mm_M3_Pad_Via
J1: PinHeader_1x06_P2.54mm_Vertical; not fitted
J2: CONF; PinHeader_1x04_P2.00mm_Vertical_SMD_Pin1Left
J3, J4, J5: Molex_Pico-Lock_504050-0591_1x05-1MP_P1.50mm_Horizontal
J6, J7: Molex_Pico-Lock_504050-0591_1x05-1MP_P1.50mm_Horizontal; not fitted
J8: PinHeader_1x04_P2.00mm_Vertical_SMD_Pin1Left
J9, J11, J12: Conn_02x03_Counter_Clockwise; Con-Amphenol-76385-303LF; not fitted
J10: Conn_02x03_Counter_Clockwise; Con-Amphenol-76385-303LF
R1: 33r; R_0805_2012Metric_Pad1.20x1.40mm_HandSolder
R2, R3, R4: 10k; R_0805_2012Metric_Pad1.20x1.40mm_HandSolder
R13: 33r; R_0805_2012Metric_Pad1.20x1.40mm_HandSolder; not fitted
R14, R15, R16: 10k; R_0805_2012Metric_Pad1.20x1.40mm_HandSolder; not fitted
SW1: Reset; ButtonSMT_CnK_KSC2_J
U1: SSD1322; Display_256x64_3.12in_board; not fitted
U2: PIC18F27Q84-I/SS; SSOP-28-5.3mm
U3: DS3231M; SOIC-16W_7.5x10.3mm_P1.27mm
U6: SN74LV1T32; SOT-23-5

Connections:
+5V: C1.1, C2.1, C3.1, C4.1, C5.1, C6.1, D1.4 (VDD), D2.4 (VDD), D3.4 (VDD), D4.4 (VDD), D5.4 (VDD), J3.1, J4.1, J5.1, J6.1, J7.1, J9.5, J10.5, J11.5, J12.5, R14.2, U6.5 (VCC); also elsewhere on the board
/Display_SSD1322/D0: U1.4 (D0), U2.11 (RC0); also elsewhere on the board
/Display_SSD1322/D1: U1.5 (D1), U2.12 (CCP2/RC1); also elsewhere on the board
/Display_SSD1322/D2: U1.6 (D2), U2.13 (CCP1/RC2); also elsewhere on the board
/Display_SSD1322/D3: U1.7 (D3), U2.14 (SCL/SCK/RC3); also elsewhere on the board
/Display_SSD1322/D4: U1.8 (D4), U2.15 (SDA/SDI/RC4); also elsewhere on the board
/Display_SSD1322/D5: U1.9 (D5), U2.16 (RC5); also elsewhere on the board
/Display_SSD1322/D6: U1.10 (D6), U2.17 (RC6); also elsewhere on the board
/Display_SSD1322/D7: U1.11 (D7), U2.18 (RC7); also elsewhere on the board
/Display_SSD1322/D/~C: U1.14 (D/~C), U2.21 (RB0); also elsewhere on the board
/Display_SSD1322/E/~RD: R3.2, U1.12 (E/~RD); also elsewhere on the board
/Display_SSD1322/R/~W: U1.13 (R/~W), U2.25 (RB4); also elsewhere on the board
/Display_SSD1322/~RES: U1.15 (~RES), U2.24 (RB3); also elsewhere on the board
GND: BT1.2 (-), C1.2, C2.2, C3.2, C4.2, C5.2, C6.2, C7.2, C8.2, C9.1, D1.1 (VSS), D2.1 (VSS), D3.1 (VSS), D4.1 (VSS), D5.1 (VSS), H1.1, H2.1, H3.1, H4.1, H5.1, H6.1, H7.1, J1.3, J2.3, J2.4, J3.5, J3.MP, J4.5, J4.MP, J5.5, J5.MP, J6.5, J6.MP, J7.5, J7.MP, J8.3, J8.4, J9.3, J10.3, J11.3, J12.3, SW1.2, SW1.4, U1.1 (GND), U1.16 (~CS), U2.8 (Vss), U2.19 (Vss), U3.5 (GND), U3.6 (GND), U3.7 (GND), U3.8 (GND), U3.9 (GND), U3.10 (GND), U3.11 (GND), U3.12 (GND), U3.13 (GND), U6.3 (GND); also elsewhere on the board
unnamed: BT1.1 (+), U3.14 (VBAT)
unnamed: C9.2, D1.2 (DIN), R1.2, R13.2, R14.1
unnamed: D1.3 (DOUT), D2.2 (DIN)
unnamed: D2.3 (DOUT), D3.2 (DIN)
unnamed: D3.3 (DOUT), D4.2 (DIN)
unnamed: D4.3 (DOUT), D5.2 (DIN)
unnamed: J1.1, R2.2, SW1.1, SW1.3, U2.1 (~MCLR/RE3)
unnamed: J1.4, U2.28 (ICSPDAT/RB7)
unnamed: J1.5, U2.27 (ICSPCLK/RB6)
unnamed: J2.1, J2.2, U2.9 (RA7)
unnamed: J8.1, J8.2, R4.1, U3.4 (~RST)
unnamed: J3.3, J4.3, J5.3, J6.3, J7.3, J9.1, J10.1, J11.1, J12.1, R16.1, U2.23 (RB2), U3.16 (SCL)
unnamed: J3.4, J4.4, J5.4, J6.4, J7.4, J9.2, J10.2, J11.2, J12.2, R15.1, U2.22 (RB1), U3.15 (SDA)
unnamed: R13.1, U2.26 (RB5), U6.1 (~OE), U6.2 (A)
unnamed: R1.1, U6.4 (Y)
VDD: C7.1, C8.1, J1.2, J3.2, J4.2, J5.2, J6.2, J7.2, J9.6, J10.6, J11.6, J12.6, R2.1, R3.1, R4.2, R15.2, R16.2, U1.2 (V_{CC}), U2.20 (Vdd), U3.2 (VCC); also elsewhere on the board

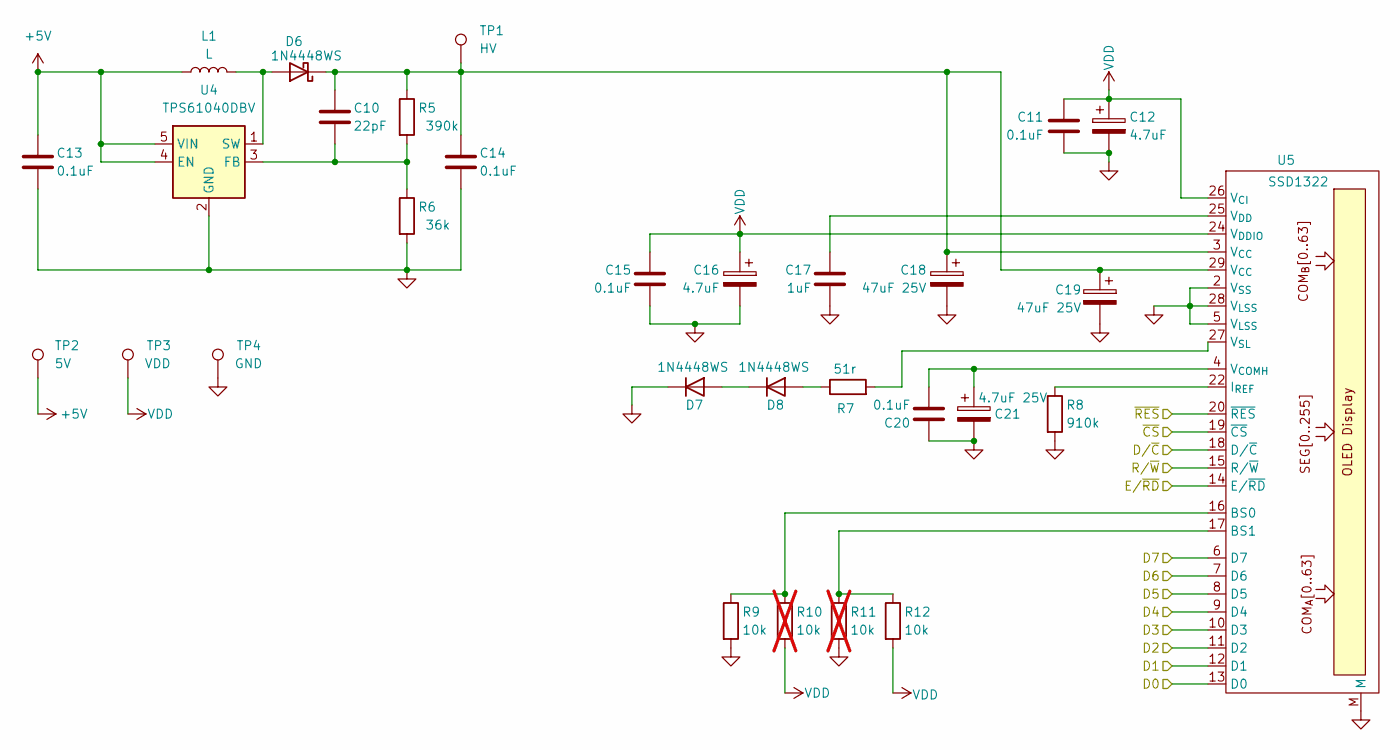
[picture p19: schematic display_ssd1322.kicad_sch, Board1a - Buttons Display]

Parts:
C10: 22pF; C_0805_2012Metric_Pad1.18x1.45mm_HandSolder
C11, C13, C15: 0.1uF; C_0805_2012Metric_Pad1.18x1.45mm_HandSolder
C12, C16: 4.7uF; CP_EIA-3528-12_Kemet-T_HandSolder
C14, C20: 0.1uF; C_0603_1608Metric_Pad1.08x0.95mm_HandSolder
C17: 1uF; C_0603_1608Metric_Pad1.08x0.95mm_HandSolder
C18, C19: 47uF 25V; CP_EIA-7343-31_Kemet-D_HandSolder
C21: 4.7uF 25V; CP_EIA-3216-18_Kemet-A_HandSolder
D6, D7, D8: 1N4448WS; D_SOD-323_HandSoldering
L1: L; L_Abracon_ASPI-3012S
R5: 390k; R_0805_2012Metric_Pad1.20x1.40mm_HandSolder
R6: 36k; R_0805_2012Metric_Pad1.20x1.40mm_HandSolder
R7: 51r; R_0805_2012Metric_Pad1.20x1.40mm_HandSolder
R8: 910k; R_0805_2012Metric_Pad1.20x1.40mm_HandSolder
R9, R12: 10k; R_0805_2012Metric_Pad1.20x1.40mm_HandSolder
R10, R11: 10k; R_0805_2012Metric_Pad1.20x1.40mm_HandSolder; not fitted
TP1: HV; TestPoint_Pad_D2.0mm
TP2: 5V; TestPoint_Pad_D2.0mm
TP3: VDD; TestPoint_Pad_D2.0mm
TP4: GND; TestPoint_Pad_D2.0mm
U4: TPS61040DBV; SOT-23-5
U5: SSD1322; Display_256x64_3.12in_flip

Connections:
+5V: C13.1, L1.1, TP2.1, U4.4 (EN), U4.5 (VIN); also elsewhere on the board
/Display_SSD1322/D0: U5.13 (D0); also elsewhere on the board
/Display_SSD1322/D1: U5.12 (D1); also elsewhere on the board
/Display_SSD1322/D2: U5.11 (D2); also elsewhere on the board
/Display_SSD1322/D3: U5.10 (D3); also elsewhere on the board
/Display_SSD1322/D4: U5.9 (D4); also elsewhere on the board
/Display_SSD1322/D5: U5.8 (D5); also elsewhere on the board
/Display_SSD1322/D6: U5.7 (D6); also elsewhere on the board
/Display_SSD1322/D7: U5.6 (D7); also elsewhere on the board
/Display_SSD1322/D/~C: U5.18 (D/~C); also elsewhere on the board
/Display_SSD1322/E/~RD: U5.14 (E/~RD); also elsewhere on the board
/Display_SSD1322/R/~W: U5.15 (R/~W); also elsewhere on the board
/Display_SSD1322/~RES: U5.20 (~RES); also elsewhere on the board
GND: C11.2, C12.2, C13.2, C14.2, C15.2, C16.2, C17.2, C18.2, C19.2, C20.1, C21.2, D7.1 (K), R6.2, R8.2, R9.2, R11.2, TP4.1, U4.2 (GND), U5.2 (V_{SS}), U5.5 (V_{LSS}), U5.19 (~CS), U5.28 (V_{LSS}), U5.M; also elsewhere on the board
unnamed: D6.2 (A), L1.2, U4.1 (SW)
unnamed: C10.1, C14.1, C18.1, C19.1, D6.1 (K), R5.1, TP1.1, U5.3 (V_{CC}), U5.29 (V_{CC})
unnamed: D7.2 (A), D8.1 (K)
unnamed: D8.2 (A), R7.1
unnamed: C10.2, R5.2, R6.1, U4.3 (FB)
unnamed: R9.1, R10.1, U5.16 (BS0)
unnamed: R11.1, R12.1, U5.17 (BS1)
unnamed: R8.1, U5.22 (I_{REF})
unnamed: C20.2, C21.1, U5.4 (V_{COMH})
unnamed: C17.1, U5.25 (V_{DD})
unnamed: R7.2, U5.27 (V_{SL})
VDD: C11.1, C12.1, C15.1, C16.1, R10.2, R12.2, TP3.1, U5.24 (V_{DDIO}), U5.26 (V_{CI}); also elsewhere on the board

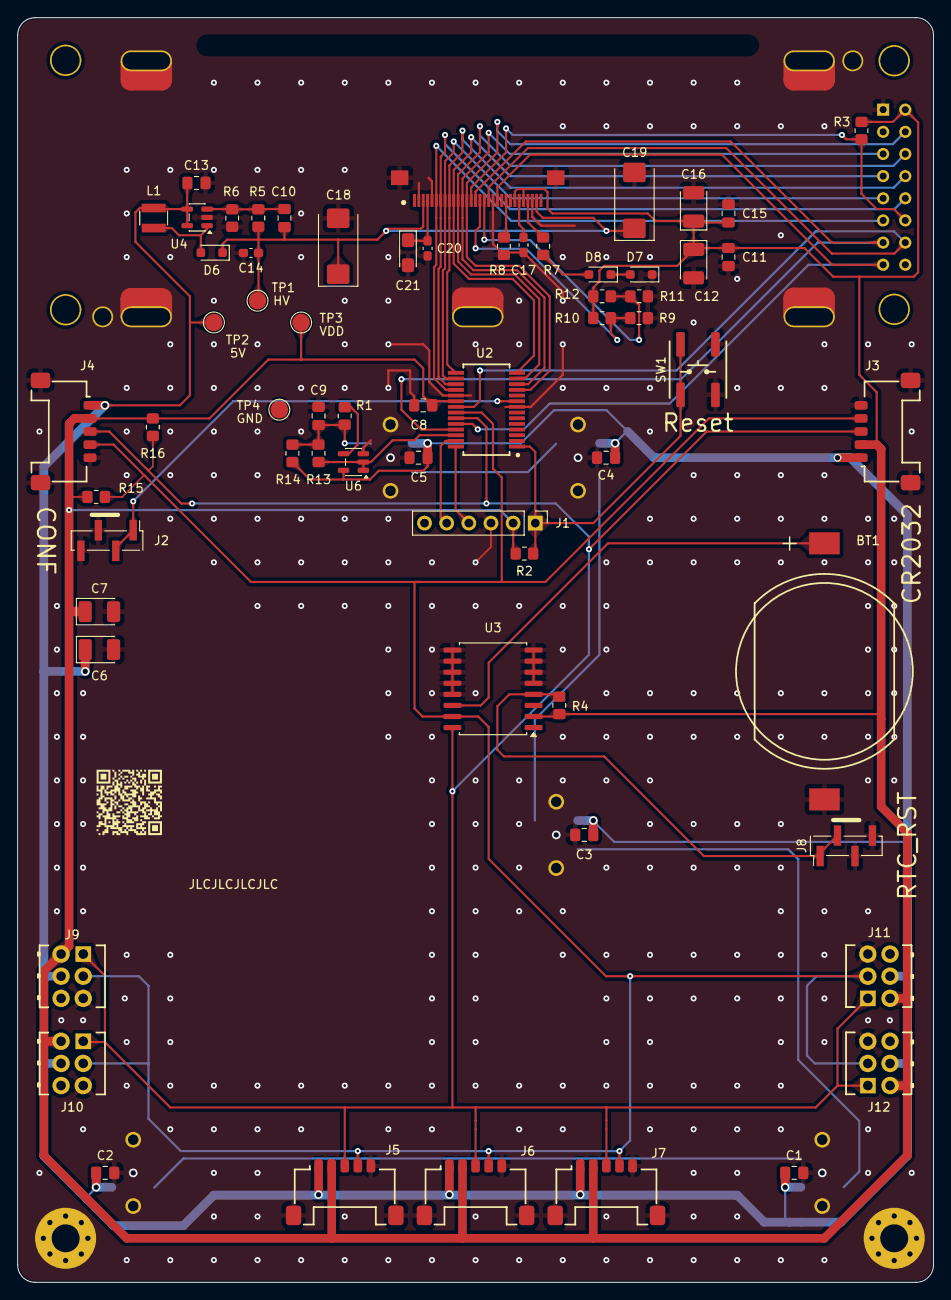
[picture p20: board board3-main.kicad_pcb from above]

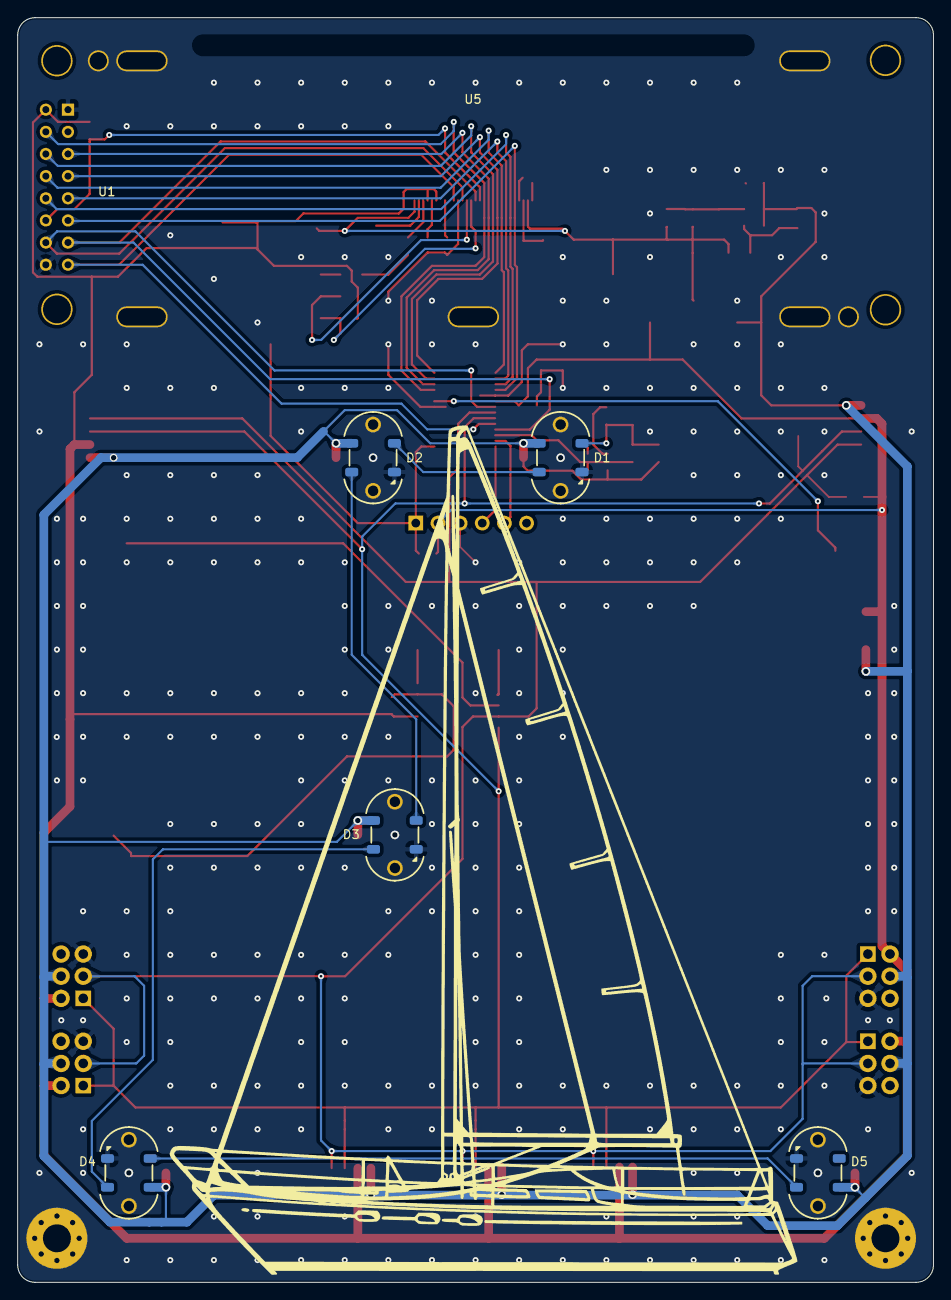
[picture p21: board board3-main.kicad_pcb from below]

Board: 2 copper layers, 105.0 x 145.0 mm, 77 parts (12 on the bottom side), 41 nets.

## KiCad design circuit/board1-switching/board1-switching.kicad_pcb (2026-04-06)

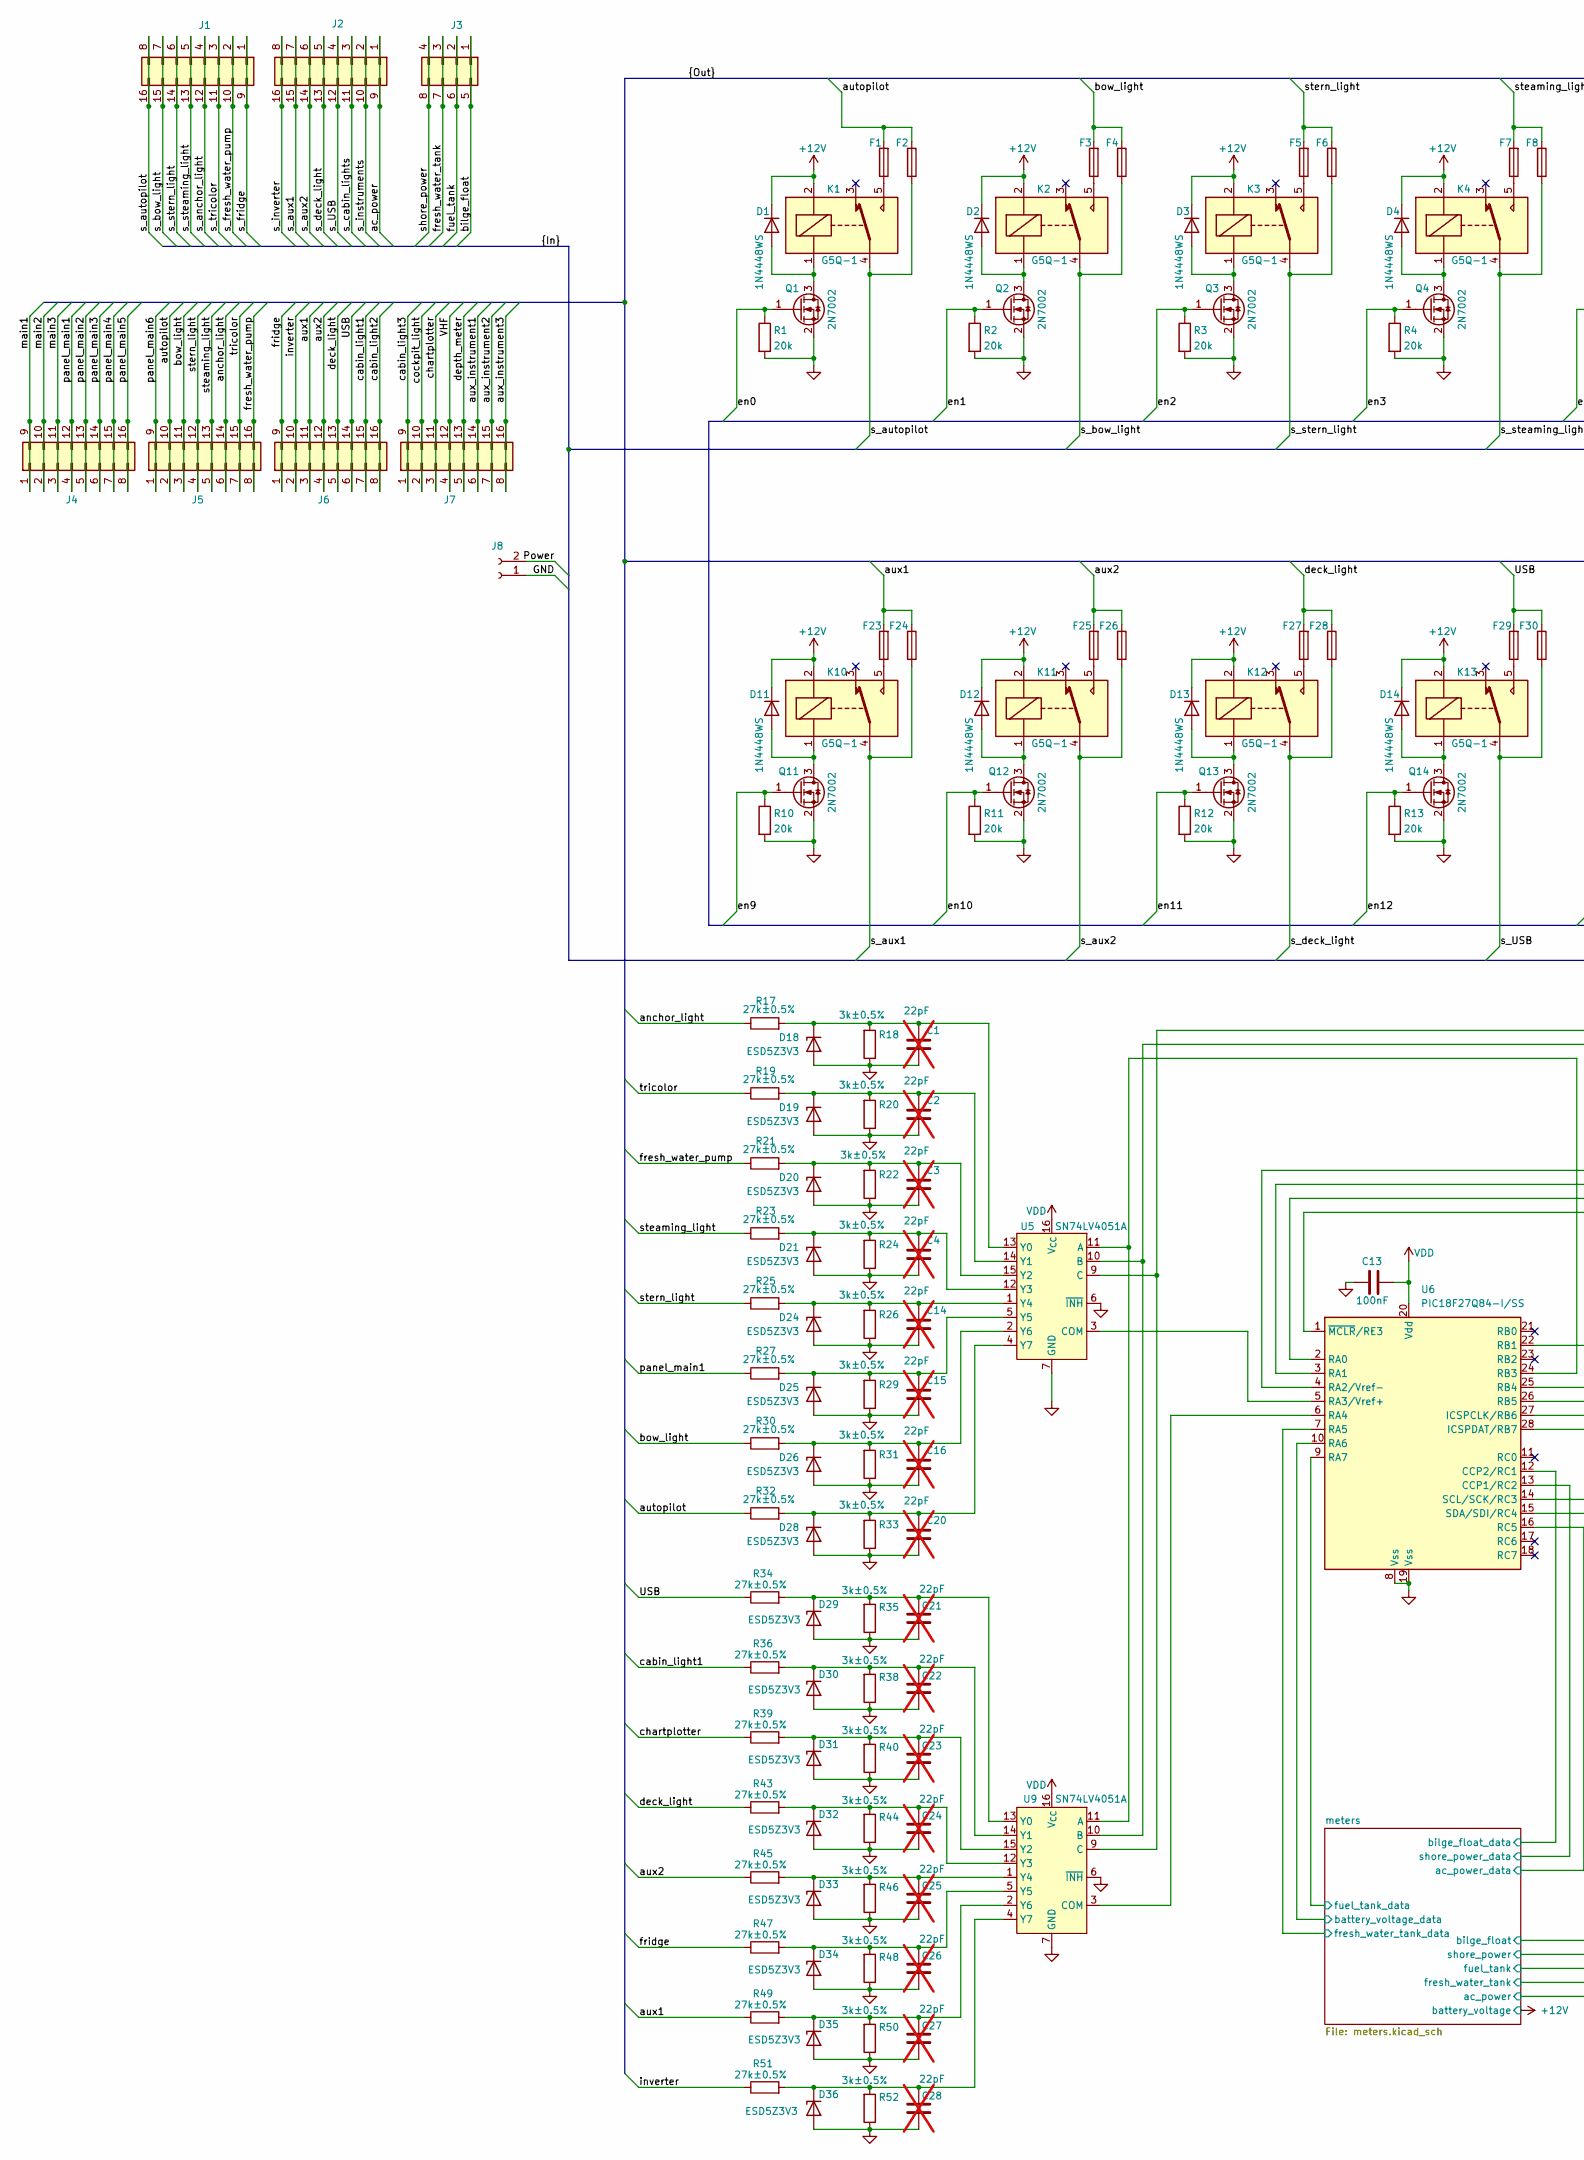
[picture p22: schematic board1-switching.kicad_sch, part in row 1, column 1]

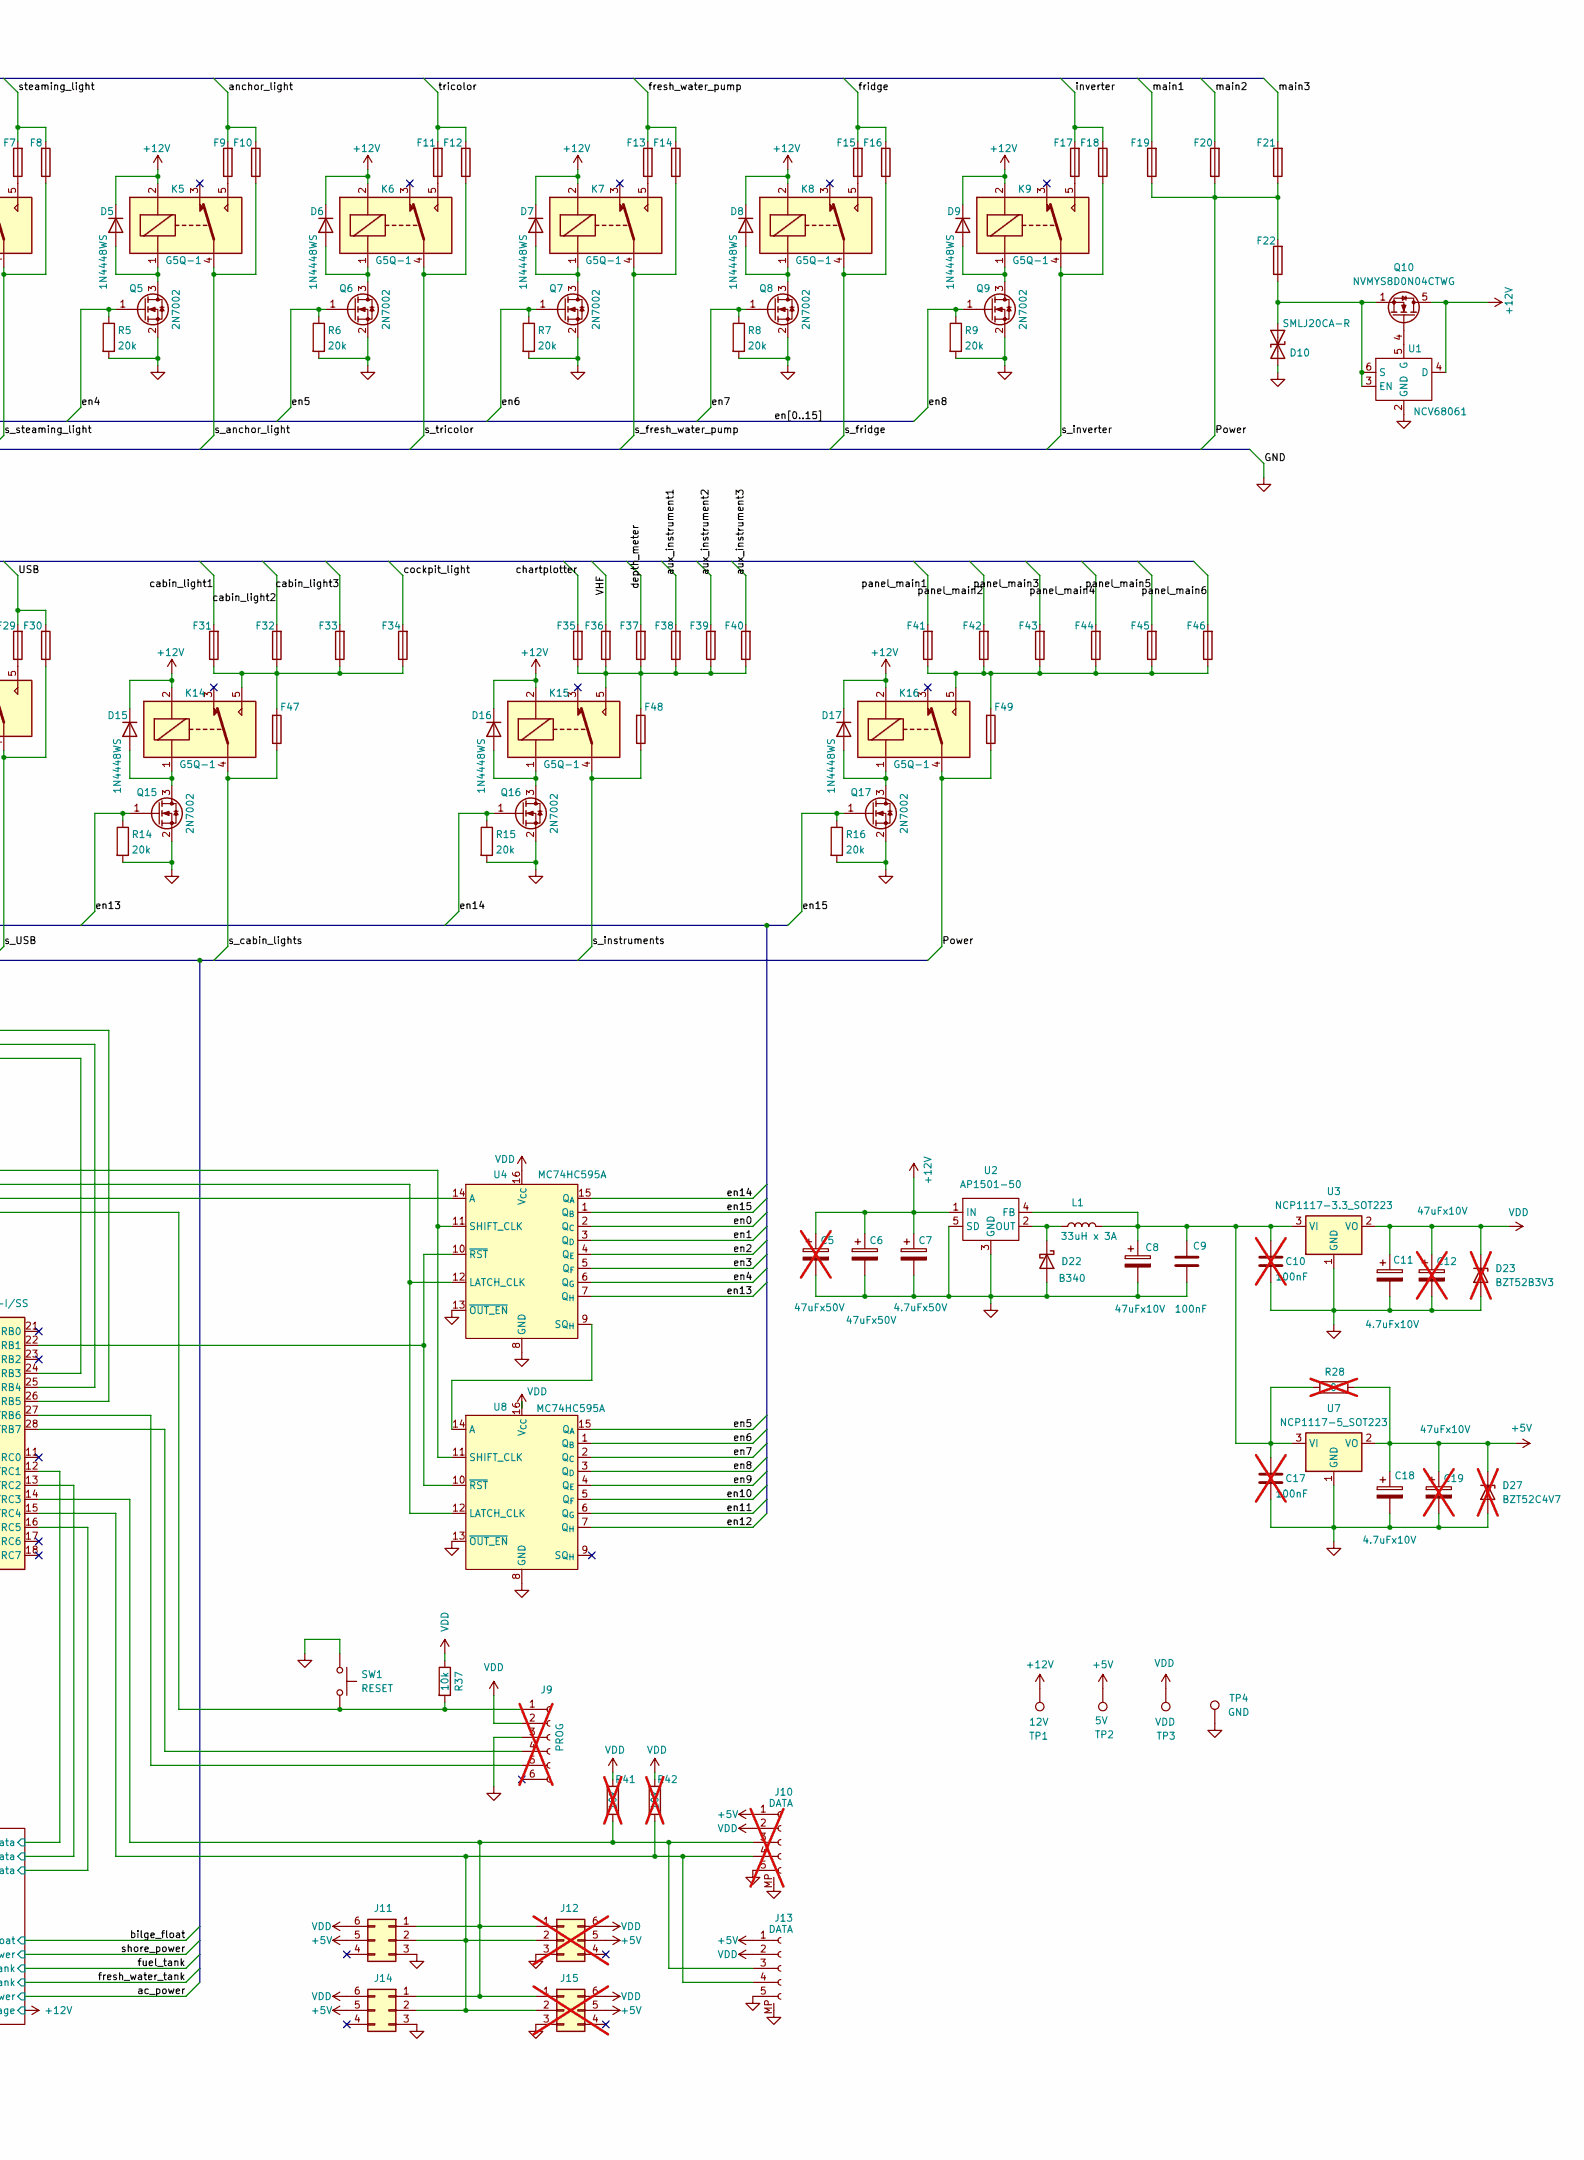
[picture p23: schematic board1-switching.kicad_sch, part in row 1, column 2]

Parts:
C1, C2, C3, C4, C14, C15, C16, C20, C21, C22, C23, C24, C25, C26, C27, C28: 22pF; C_0805_2012Metric_Pad1.18x1.45mm_HandSolder; not fitted
C5: 47uFx50V; CP_Elec_8x6.5; not fitted
C6: 47uFx50V; CP_Elec_8x6.5
C7: 4.7uFx50V; C_Elec_5x5.4
C8: 47uFx10V; CP_EIA-3528-12_Kemet-T_HandSolder
C9, C13: 100nF; C_0805_2012Metric_Pad1.18x1.45mm_HandSolder
C10, C17: 100nF; C_0805_2012Metric_Pad1.18x1.45mm_HandSolder; not fitted
C11, C18: 4.7uFx10V; CP_EIA-3216-10_Kemet-I_HandSolder
C12, C19: 47uFx10V; CP_EIA-3528-12_Kemet-T_HandSolder; not fitted
D1, D2, D3, D4, D5, D6, D7, D8, D9, D11, D12, D13, D14, D15, D16, D17: 1N4448WS; D_SOD-323_HandSoldering
D10: SMLJ20CA-R; D_SMC
D18, D19, D20, D21, D24, D25, D26, D28, D29, D30, D31, D32, D33, D34, D35, D36: ESD5Z3V3; D_SOD-523
D22: B340; D_B340-SMAF
D23: BZT52B3V3; D_SOD-123F; not fitted
D27: BZT52C4V7; D_SOD-123F; not fitted
F1, F2, F3, F4, F5, F6, F7, F8, F9, F10, F11, F12, F13, F14, F15, F16, F17, F18, F19, F20, F21, F22, F23, F24, F25, F26, F27, F28, F29, F30, F31, F32, F33, F34, F35, F36, F37, F38, F39, F40, F41, F42, F43, F44, F45, F46, F47, F48, F49: Fuse-Keystone-3557-2
J1, J2, J4, J5, J6, J7: Con_2x08_Amphenol-QT08CDP
J3: Con_2x04_Amphenol-QT04CDP
J8: J_Molex_38710-6302
J9: PinHeader_1x06_P2.54mm_Vertical; not fitted
J10: Molex_Pico-Lock_504050-0591_1x05-1MP_P1.50mm_Horizontal; not fitted
J11, J14: Conn_02x03_Counter_Clockwise; Con-Amphenol-76385-303LF
J12, J15: Conn_02x03_Counter_Clockwise; Con-Amphenol-76385-303LF; not fitted
J13: Molex_Pico-Lock_504050-0591_1x05-1MP_P1.50mm_Horizontal
K1, K2, K3, K4, K5, K6, K7, K8, K9, K10, K11, K12, K13, K14, K15, K16: G5Q-1; Relay-TE-V23086-C1xxx
L1: 33uH x 3A; L_Abracon_AMDLA1004S-330MT
Q1, Q2, Q3, Q4, Q5, Q6, Q7, Q8, Q9, Q11, Q12, Q13, Q14, Q15, Q16, Q17: 2N7002; SOT-23
Q10: NVMYS8D0N04CTWG; LFPAK4_4.90x4.15x1.15MM_1.27P
R1, R2, R3, R4, R5, R6, R7, R8, R9, R10, R11, R12, R13, R14, R15, R16: 20k; R_0805_2012Metric_Pad1.20x1.40mm_HandSolder
R17, R19, R21, R23, R25, R27, R30, R32, R34, R36, R39, R43, R45, R47, R49, R51: 27k±0.5%; R_0805_2012Metric_Pad1.20x1.40mm_HandSolder
R18, R20, R22, R24, R26, R29, R31, R33, R35, R38, R40, R44, R46, R48, R50, R52: 3k±0.5%; R_0805_2012Metric_Pad1.20x1.40mm_HandSolder
R28: 0; R_0805_2012Metric_Pad1.20x1.40mm_HandSolder; not fitted
R37: 10k; R_0805_2012Metric_Pad1.20x1.40mm_HandSolder
R41, R42: 10k; R_0805_2012Metric_Pad1.20x1.40mm_HandSolder; not fitted
SW1: RESET; ButtonSMT_CnK_KSC2_J
TP1: 12V; TestPoint_Pad_D2.0mm
TP2: 5V; TestPoint_Pad_D2.0mm
TP3: VDD; TestPoint_Pad_D2.0mm
TP4: GND; TestPoint_Pad_D2.0mm
U1: NCV68061; TSOP-6_3.00x1.5x0.90mm_P0.95mm
U2: AP1501-50; TO-263-5_TabPin3
U3: NCP1117-3.3_SOT223; SOT-223-3_TabPin2
U4, U8: MC74HC595A; SOIC-16_3.9x9.9mm_P1.27mm
U5, U9: SN74LV4051A; SOIC-16_3.9x9.9mm_P1.27mm
U6: PIC18F27Q84-I/SS; SSOP-28-5.3mm
U7: NCP1117-5_SOT223; SOT-223-3_TabPin2

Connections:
+5V: C18.1, C19.1, D27.1 (K), J10.1, J11.5, J12.5, J13.1, J14.5, J15.5, R28.1, TP2.1, U7.2 (VO); also elsewhere on the board
+12V: C5.1, C6.1, C7.1, D1.1 (K), D2.1 (K), D3.1 (K), D4.1 (K), D5.1 (K), D6.1 (K), D7.1 (K), D8.1 (K), D9.1 (K), D11.1 (K), D12.1 (K), D13.1 (K), D14.1 (K), D15.1 (K), D16.1 (K), D17.1 (K), K1.2, K2.2, K3.2, K4.2, K5.2, K6.2, K7.2, K8.2, K9.2, K10.2, K11.2, K12.2, K13.2, K14.2, K15.2, K16.2, Q10.5 (D), TP1.1, U1.4 (D), U2.1 (IN); also elsewhere on the board
/Power: F19.1, F19.2, F20.1, F20.2, F21.1, F21.2, F22.3, F22.4, F49.1, F49.2, J8.2, K16.4
/USB: F29.3, F29.4, F30.3, F30.4, J6.6, J6.14, R34.1
/VHF: F36.3, F36.4, J7.4, J7.12
/ac_power: J2.1, J2.9; also elsewhere on the board
/anchor_light: F9.3, F9.4, F10.3, F10.4, J5.6, J5.14, R17.1
/autopilot: F1.3, F1.4, F2.3, F2.4, J5.2, J5.10, R32.1
/aux1: F23.3, F23.4, F24.3, F24.4, J6.3, J6.11, R49.1
/aux2: F25.3, F25.4, F26.3, F26.4, J6.4, J6.12, R45.1
/aux_instrument1: F38.3, F38.4, J7.6, J7.14
/aux_instrument2: F39.3, F39.4, J7.7, J7.15
/aux_instrument3: F40.3, F40.4, J7.8, J7.16
/bilge_float: J3.1, J3.5; also elsewhere on the board
/bow_light: F3.3, F3.4, F4.3, F4.4, J5.3, J5.11, R30.1
/cabin_light1: F31.3, F31.4, J6.7, J6.15, R36.1
/cabin_light2: F32.3, F32.4, J6.8, J6.16
/cabin_light3: F33.3, F33.4, J7.1, J7.9
/chartplotter: F35.3, F35.4, J7.3, J7.11, R39.1
/cockpit_light: F34.3, F34.4, J7.2, J7.10
/deck_light: F27.3, F27.4, F28.3, F28.4, J6.5, J6.13, R43.1
/depth_meter: F37.3, F37.4, J7.5, J7.13
/en0: Q1.1 (G), R1.1, U4.2 (Q_{C})
/en1: Q2.1 (G), R2.1, U4.3 (Q_{D})
/en2: Q3.1 (G), R3.1, U4.4 (Q_{E})
/en3: Q4.1 (G), R4.1, U4.5 (Q_{F})
/en4: Q5.1 (G), R5.1, U4.6 (Q_{G})
/en5: Q6.1 (G), R6.1, U8.15 (Q_{A})
/en6: Q7.1 (G), R7.1, U8.1 (Q_{B})
/en7: Q8.1 (G), R8.1, U8.2 (Q_{C})
/en8: Q9.1 (G), R9.1, U8.3 (Q_{D})
/en9: Q11.1 (G), R10.1, U8.4 (Q_{E})
/en10: Q12.1 (G), R11.1, U8.5 (Q_{F})
/en11: Q13.1 (G), R12.1, U8.6 (Q_{G})
/en12: Q14.1 (G), R13.1, U8.7 (Q_{H})
/en13: Q15.1 (G), R14.1, U4.7 (Q_{H})
/en14: Q16.1 (G), R15.1, U4.15 (Q_{A})
/en15: Q17.1 (G), R16.1, U4.1 (Q_{B})
/fresh_water_pump: F13.3, F13.4, F14.3, F14.4, J5.8, J5.16, R21.1
/fresh_water_tank: J3.3, J3.7; also elsewhere on the board
/fridge: F15.3, F15.4, F16.3, F16.4, J6.1, J6.9, R47.1
/fuel_tank: J3.2, J3.6; also elsewhere on the board
/inverter: F17.3, F17.4, F18.3, F18.4, J6.2, J6.10, R51.1
/main1: F19.3, F19.4, J4.1, J4.9
/main2: F20.3, F20.4, J4.2, J4.10
/main3: F21.3, F21.4, J4.3, J4.11
/meters/ac_power_data: U6.16 (RC5); also elsewhere on the board
/meters/battery_voltage_data: U6.10 (RA6); also elsewhere on the board
/meters/bilge_float_data: U6.12 (CCP2/RC1); also elsewhere on the board
/meters/fresh_water_tank_data: U6.7 (RA5); also elsewhere on the board
/meters/fuel_tank_data: U6.9 (RA7); also elsewhere on the board
/meters/shore_power_data: U6.13 (CCP1/RC2); also elsewhere on the board
/panel_main1: F41.3, F41.4, J4.4, J4.12, R27.1
/panel_main2: F42.3, F42.4, J4.5, J4.13
/panel_main3: F43.3, F43.4, J4.6, J4.14
/panel_main4: F44.3, F44.4, J4.7, J4.15
/panel_main5: F45.3, F45.4, J4.8, J4.16
/panel_main6: F46.3, F46.4, J5.1, J5.9
/s_USB: F30.1, F30.2, J2.4, J2.12, K13.4
/s_anchor_light: F10.1, F10.2, J1.4, J1.12, K5.4
/s_autopilot: F2.1, F2.2, J1.8, J1.16, K1.4
/s_aux1: F24.1, F24.2, J2.7, J2.15, K10.4
/s_aux2: F26.1, F26.2, J2.6, J2.14, K11.4
/s_bow_light: F4.1, F4.2, J1.7, J1.15, K2.4
/s_cabin_lights: F47.1, F47.2, J2.3, J2.11, K14.4
/s_deck_light: F28.1, F28.2, J2.5, J2.13, K12.4
/s_fresh_water_pump: F14.1, F14.2, J1.2, J1.10, K7.4
/s_fridge: F16.1, F16.2, J1.1, J1.9, K8.4
/s_instruments: F48.1, F48.2, J2.2, J2.10, K15.4
/s_inverter: F18.1, F18.2, J2.8, J2.16, K9.4
/s_steaming_light: F8.1, F8.2, J1.5, J1.13, K4.4
/s_stern_light: F6.1, F6.2, J1.6, J1.14, K3.4
/s_tricolor: F12.1, F12.2, J1.3, J1.11, K6.4
/shore_power: J3.4, J3.8; also elsewhere on the board
/steaming_light: F7.3, F7.4, F8.3, F8.4, J5.5, J5.13, R23.1
/stern_light: F5.3, F5.4, F6.3, F6.4, J5.4, J5.12, R25.1
/tricolor: F11.3, F11.4, F12.3, F12.4, J5.7, J5.15, R19.1
GND: C1.1, C2.1, C3.1, C4.1, C5.2, C6.2, C7.2, C8.2, C9.2, C10.2, C11.2, C12.2, C13.2, C14.1, C15.1, C16.1, C17.2, C18.2, C19.2, C20.1, C21.1, C22.1, C23.1, C24.1, C25.1, C26.1, C27.1, C28.1, D10.2 (A2), D18.2 (A), D19.2 (A), D20.2 (A), D21.2 (A), D22.2 (A), D23.2 (A), D24.2 (A), D25.2 (A), D26.2 (A), D27.2 (A), D28.2 (A), D29.2 (A), D30.2 (A), D31.2 (A), D32.2 (A), D33.2 (A), D34.2 (A), D35.2 (A), D36.2 (A), J8.1, J9.3, J10.5, J10.MP, J11.3, J12.3, J13.5, J13.MP, J14.3, J15.3, Q1.2 (S), Q2.2 (S), Q3.2 (S), Q4.2 (S), Q5.2 (S), Q6.2 (S), Q7.2 (S), Q8.2 (S), Q9.2 (S), Q11.2 (S), Q12.2 (S), Q13.2 (S), Q14.2 (S), Q15.2 (S), Q16.2 (S), Q17.2 (S), R1.2, R2.2, R3.2, R4.2, R5.2, R6.2, R7.2, R8.2, R9.2, R10.2, R11.2, R12.2, R13.2, R14.2, R15.2, R16.2, R18.1, R20.1, R22.1, R24.1, R26.1, R29.1, R31.1, R33.1, R35.1, R38.1, R40.1, R44.1, R46.1, R48.1, R50.1, R52.1, SW1.1, SW1.3, TP4.1, U1.2 (GND), U2.3 (GND), U2.5 (SD), U3.1 (GND), U4.8 (GND), U4.13 (~OUT_EN), U5.6 (~INH), U5.7 (GND), U5.8 (GND), U6.8 (Vss), U6.19 (Vss), U7.1 (GND), U8.8 (GND), U8.13 (~OUT_EN), U9.6 (~INH), U9.7 (GND), U9.8 (GND); also elsewhere on the board
unnamed: D1.2 (A), K1.1, Q1.3 (D)
unnamed: D2.2 (A), K2.1, Q2.3 (D)
unnamed: D3.2 (A), K3.1, Q3.3 (D)
unnamed: D4.2 (A), K4.1, Q4.3 (D)
unnamed: D5.2 (A), K5.1, Q5.3 (D)
unnamed: D6.2 (A), K6.1, Q6.3 (D)
unnamed: D7.2 (A), K7.1, Q7.3 (D)
unnamed: D8.2 (A), K8.1, Q8.3 (D)
unnamed: D9.2 (A), K9.1, Q9.3 (D)
unnamed: D10.1 (A1), F22.1, F22.2, Q10.1 (S), Q10.2 (S), Q10.3 (S), U1.3 (EN), U1.6 (S)
unnamed: D11.2 (A), K10.1, Q11.3 (D)
unnamed: D12.2 (A), K11.1, Q12.3 (D)
unnamed: D13.2 (A), K12.1, Q13.3 (D)
unnamed: D14.2 (A), K13.1, Q14.3 (D)
unnamed: D15.2 (A), K14.1, Q15.3 (D)
unnamed: D16.2 (A), K15.1, Q16.3 (D)
unnamed: D17.2 (A), K16.1, Q17.3 (D)
unnamed: C1.2, D18.1 (K), R17.2, R18.2, U5.13 (Y0)
unnamed: C2.2, D19.1 (K), R19.2, R20.2, U5.14 (Y1)
unnamed: C3.2, D20.1 (K), R21.2, R22.2, U5.15 (Y2)
unnamed: C4.2, D21.1 (K), R23.2, R24.2, U5.12 (Y3)
unnamed: D22.1 (K), L1.1, U2.2 (OUT)
unnamed: C14.2, D24.1 (K), R25.2, R26.2, U5.1 (Y4)
unnamed: C15.2, D25.1 (K), R27.2, R29.2, U5.5 (Y5)
unnamed: C16.2, D26.1 (K), R30.2, R31.2, U5.2 (Y6)
unnamed: C20.2, D28.1 (K), R32.2, R33.2, U5.4 (Y7)
unnamed: C21.2, D29.1 (K), R34.2, R35.2, U9.13 (Y0)
unnamed: C22.2, D30.1 (K), R36.2, R38.2, U9.14 (Y1)
unnamed: C23.2, D31.1 (K), R39.2, R40.2, U9.15 (Y2)
unnamed: C24.2, D32.1 (K), R43.2, R44.2, U9.12 (Y3)
unnamed: C25.2, D33.1 (K), R45.2, R46.2, U9.1 (Y4)
unnamed: C26.2, D34.1 (K), R47.2, R48.2, U9.5 (Y5)
unnamed: C27.2, D35.1 (K), R49.2, R50.2, U9.2 (Y6)
unnamed: C28.2, D36.1 (K), R51.2, R52.2, U9.4 (Y7)
unnamed: F1.1, F1.2, K1.5
unnamed: F3.1, F3.2, K2.5
unnamed: F5.1, F5.2, K3.5
unnamed: F7.1, F7.2, K4.5
unnamed: F9.1, F9.2, K5.5
unnamed: F11.1, F11.2, K6.5
unnamed: F13.1, F13.2, K7.5
unnamed: F15.1, F15.2, K8.5
unnamed: F17.1, F17.2, K9.5
unnamed: F23.1, F23.2, K10.5
unnamed: F25.1, F25.2, K11.5
unnamed: F27.1, F27.2, K12.5
unnamed: F29.1, F29.2, K13.5
unnamed: F31.1, F31.2, F32.1, F32.2, F33.1, F33.2, F34.1, F34.2, F47.3, F47.4, K14.5
unnamed: F35.1, F35.2, F36.1, F36.2, F37.1, F37.2, F38.1, F38.2, F39.1, F39.2, F40.1, F40.2, F48.3, F48.4, K15.5
unnamed: F41.1, F41.2, F42.1, F42.2, F43.1, F43.2, F44.1, F44.2, F45.1, F45.2, F46.1, F46.2, F49.3, F49.4, K16.5
unnamed: J9.1, R37.2, SW1.2, SW1.4, U6.1 (~MCLR/RE3)
unnamed: J9.4, U6.28 (ICSPDAT/RB7)
unnamed: J9.5, U6.27 (ICSPCLK/RB6)
unnamed: J10.3, J11.1, J12.1, J13.3, J14.1, J15.1, R41.2, U6.14 (SCL/SCK/RC3)
unnamed: J10.4, J11.2, J12.2, J13.4, J14.2, J15.2, R42.2, U6.15 (SDA/SDI/RC4)
unnamed: Q10.4 (G), U1.5 (G)
unnamed: C8.1, C9.1, C10.1, C17.1, L1.2, R28.2, U2.4 (FB), U3.3 (VI), U7.3 (VI)
unnamed: U4.14 (A), U6.2 (RA0)
unnamed: U4.12 (LATCH_CLK), U6.3 (RA1), U8.12 (LATCH_CLK)
unnamed: U4.11 (SHIFT_CLK), U6.4 (RA2/Vref-), U8.11 (SHIFT_CLK)
unnamed: U4.9 (SQ_{H}), U8.14 (A)
unnamed: U4.10 (~RST), U6.22 (RB1), U8.10 (~RST)
unnamed: U5.11 (A), U6.24 (RB3), U9.11 (A)
unnamed: U5.10 (B), U6.25 (RB4), U9.10 (B)
unnamed: U5.9 (C), U6.26 (RB5), U9.9 (C)
unnamed: U5.3 (COM), U6.5 (RA3/Vref+)
unnamed: U6.6 (RA4), U9.3 (COM)
VDD: C11.1, C12.1, C13.1, D23.1 (K), J9.2, J10.2, J11.6, J12.6, J13.2, J14.6, J15.6, R37.1, R41.1, R42.1, TP3.1, U3.2 (VO), U4.16 (V_{CC}), U5.16 (V_{CC}), U6.20 (Vdd), U8.16 (V_{CC}), U9.16 (V_{CC}); also elsewhere on the board

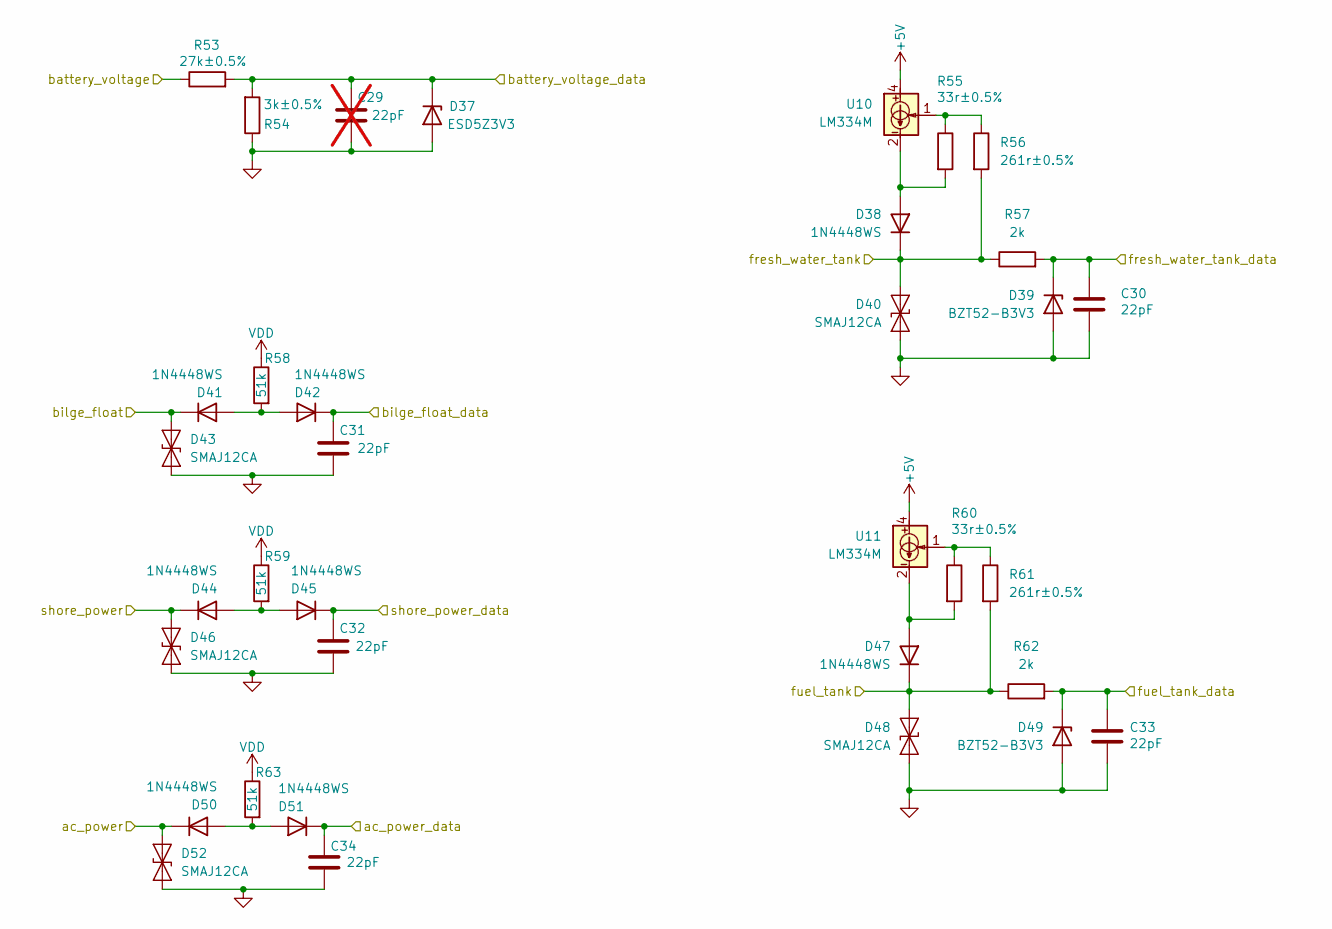
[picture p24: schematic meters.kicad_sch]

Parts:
C29: 22pF; C_0805_2012Metric_Pad1.18x1.45mm_HandSolder; not fitted
C30, C31, C32, C33, C34: 22pF; C_0805_2012Metric_Pad1.18x1.45mm_HandSolder
D37: ESD5Z3V3; D_SOD-523
D38, D41, D42, D44, D45, D47, D50, D51: 1N4448WS; D_SOD-323_HandSoldering
D39, D49: BZT52-B3V3; D_SOD-123
D40, D43, D46, D48, D52: SMAJ12CA; D_SMA
R53: 27k±0.5%; R_0805_2012Metric_Pad1.20x1.40mm_HandSolder
R54: 3k±0.5%; R_0805_2012Metric_Pad1.20x1.40mm_HandSolder
R55, R60: 33r±0.5%; R_0805_2012Metric_Pad1.20x1.40mm_HandSolder
R56, R61: 261r±0.5%; R_0805_2012Metric_Pad1.20x1.40mm_HandSolder
R57, R62: 2k; R_0805_2012Metric_Pad1.20x1.40mm_HandSolder
R58, R59, R63: 51k; R_0805_2012Metric_Pad1.20x1.40mm_HandSolder
U10, U11: LM334M; SOIC-8_3.9x4.9mm_P1.27mm

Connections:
+5V: U10.4, U11.4; also elsewhere on the board
+12V: R53.1; also elsewhere on the board
/ac_power: D50.1 (K), D52.2 (A2); also elsewhere on the board
/bilge_float: D41.1 (K), D43.2 (A2); also elsewhere on the board
/fresh_water_tank: D38.1 (K), D40.2 (A2), R56.2, R57.1; also elsewhere on the board
/fuel_tank: D47.1 (K), D48.2 (A2), R61.2, R62.1; also elsewhere on the board
/meters/ac_power_data: C34.1, D51.1 (K); also elsewhere on the board
/meters/battery_voltage_data: C29.2, D37.1 (K), R53.2, R54.2; also elsewhere on the board
/meters/bilge_float_data: C31.1, D42.1 (K); also elsewhere on the board
/meters/fresh_water_tank_data: C30.1, D39.1 (K), R57.2; also elsewhere on the board
/meters/fuel_tank_data: C33.1, D49.1 (K), R62.2; also elsewhere on the board
/meters/shore_power_data: C32.1, D45.1 (K); also elsewhere on the board
/shore_power: D44.1 (K), D46.2 (A2); also elsewhere on the board
GND: C29.1, C30.2, C31.2, C32.2, C33.2, C34.2, D37.2 (A), D39.2 (A), D40.1 (A1), D43.1 (A1), D46.1 (A1), D48.1 (A1), D49.2 (A), D52.1 (A1), R54.1; also elsewhere on the board
unnamed: D38.2 (A), R55.2, U10.2, U10.3, U10.6, U10.7
unnamed: D41.2 (A), D42.2 (A), R58.2
unnamed: D44.2 (A), D45.2 (A), R59.2
unnamed: D47.2 (A), R60.2, U11.2, U11.3, U11.6, U11.7
unnamed: D50.2 (A), D51.2 (A), R63.2
unnamed: R55.1, R56.1, U10.1
unnamed: R60.1, R61.1, U11.1
VDD: R58.1, R59.1, R63.1; also elsewhere on the board

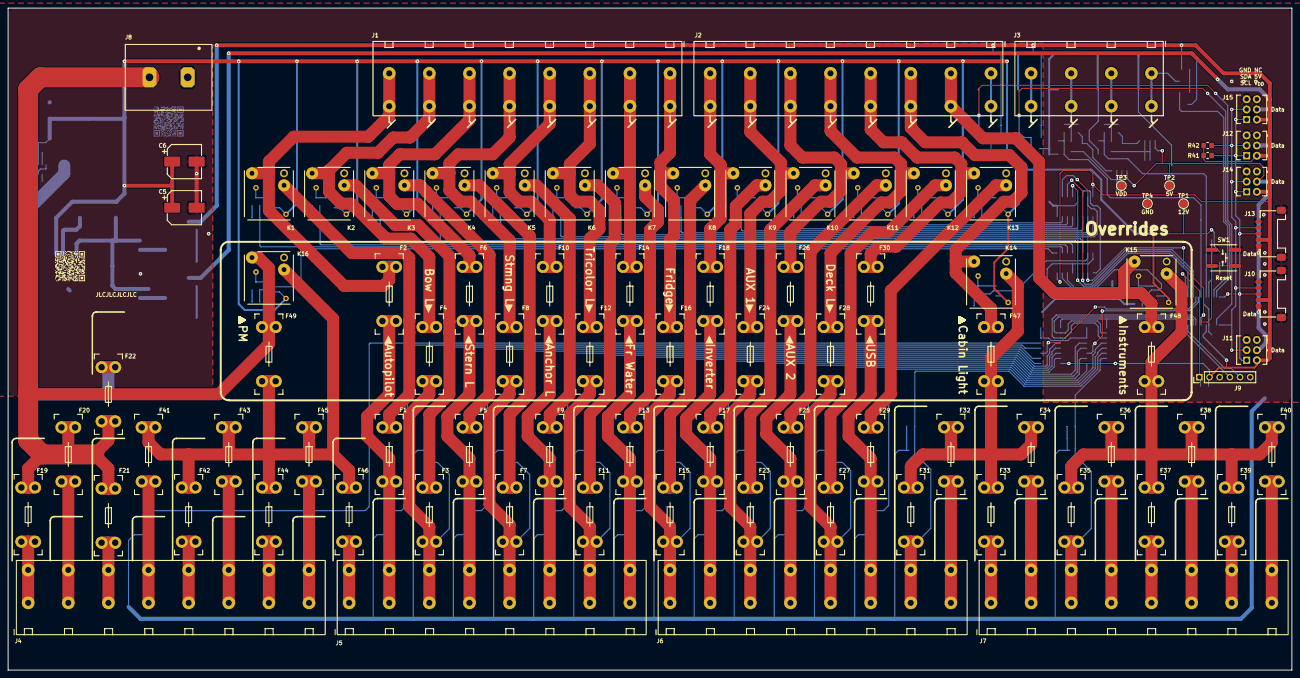
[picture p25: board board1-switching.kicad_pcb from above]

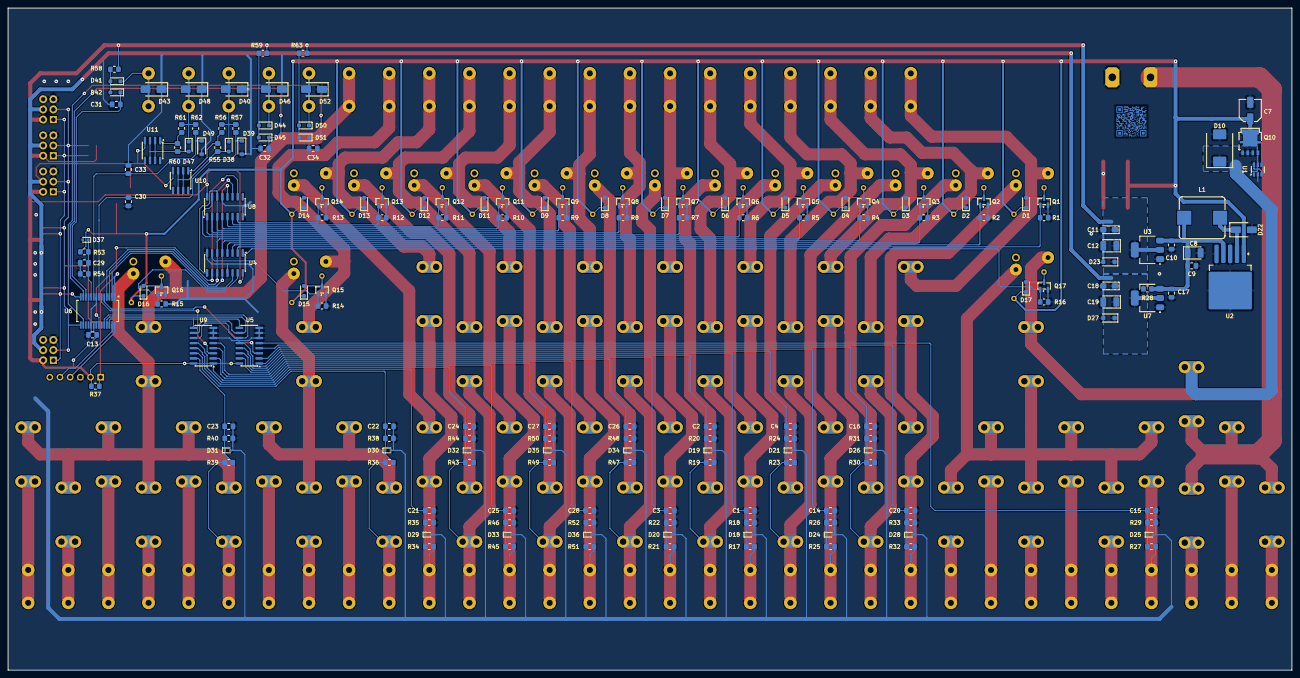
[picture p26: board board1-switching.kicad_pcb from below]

Board: 2 copper layers, 320.0 x 165.0 mm, 263 parts (174 on the bottom side), 153 nets.

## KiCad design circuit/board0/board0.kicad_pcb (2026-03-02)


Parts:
C1, C2, C3, C4, C5, C6, C7, C8, C9, C10, C11, C12, C13, C14, C15, C16, C19, C20: 100nF; C_0805_2012Metric_Pad1.18x1.45mm_HandSolder
C17: 4.7uFx50V; C_Elec_5x5.4
C18, C21: 4.7uF x 10V; CP_EIA-3216-10_Kemet-I_HandSolder
D1, D2, D4, D6, D17: DF2S16FS; D_SOD-923
D3, D8, D18, D19, D22, D23: 1N4448WS; D_SOD-323_HandSoldering
D5, D13: BZT52-B3V3; D_SOD-123
D7, D14, D20, D24: SMAJ12CA; D_SMA
D9, D10, D11, D12: LED; LED_D3.0mm
D15, D16: LiteOn_LTST-E563C; LED_LiteOn_LTST-E563C_PLCC4_5.0x5.0mm_P3.2mm
D21: B340; D_SMC
H1, H2, H3, H4: MountingHole_Pad; MountingHole_3.2mm_M3_Pad_Via
J1: PinHeader_1x06_P2.54mm_Vertical; not fitted
J2, J6, J11: Conn_01x03_Pin; PinHeader_1x03_P2.54mm_Vertical
J3, J7, J10, J12, J13, J15, J16, J17, J18, J19: Conn_01x02_Pin; PinHeader_1x02_P2.54mm_Vertical
J4, J5: Conn_02x08_Odd_Even; PinHeader_2x04_P2.54mm_Vertical
J8: Molex_Pico-Lock_504050-0591_1x05-1MP_P1.50mm_Horizontal
J9: Conn_02x03_Counter_Clockwise; Con-Amphenol-76385-303LF
J14: Conn_02x08_Odd_Even; PinHeader_2x03_P2.54mm_Vertical
L1: 33uH x 3A; L_Abracon_AMDLA1004S-330MT
R1, R3, R5, R7, R10, R12, R15, R17, R40, R43: 33k; R_0805_2012Metric_Pad1.20x1.40mm_HandSolder
R2, R6, R11, R16, R41: 100k; R_0805_2012Metric_Pad1.20x1.40mm_HandSolder
R4, R14, R34: 10k; R_0805_2012Metric_Pad1.20x1.40mm_HandSolder
R8, R25: 174r±1%; R_0805_2012Metric_Pad1.20x1.40mm_HandSolder
R9, R26: 1k37±1%; R_0805_2012Metric_Pad1.20x1.40mm_HandSolder
R13, R19, R21, R22, R23, R24, R27, R28, R29, R30, R31, R32, R33, R36, R39: 51k; R_Axial_DIN0207_L6.3mm_D2.5mm_P10.16mm_Horizontal
R18, R35: 51k±1%; R_0805_2012Metric_Pad1.20x1.40mm_HandSolder
R20, R37: 5k1±1%; R_0603_1608Metric_Pad0.98x0.95mm_HandSolder
R38: 33r; R_0805_2012Metric_Pad1.20x1.40mm_HandSolder
R42: 120r; R_0805_2012Metric_Pad1.20x1.40mm_HandSolder
R44, R45: 60r; R_0805_2012Metric_Pad1.20x1.40mm_HandSolder
R46, R48: 51k; R_0805_2012Metric_Pad1.20x1.40mm_HandSolder
R47: 20k; R_0805_2012Metric_Pad1.20x1.40mm_HandSolder
RV1, RV2: R_Potentiometer; Pot-linear-PDV
U1, U6: LM334M; SOIC-8_3.9x4.9mm_P1.27mm
U2: LMV358; SOIC-8_3.9x4.9mm_P1.27mm
U3: SN74LV4051A; SOIC-16_3.9x9.9mm_P1.27mm
U4: PIC18F27Q84-I/SS; SSOP-28-5.3mm
U5: MC74HC595A; SOIC-16_3.9x9.9mm_P1.27mm
U7: SN65HVD230; SOIC-8_3.9x4.9mm_P1.27mm
U8: AP1501-50; TO-263-5_TabPin3
U9: NCP1117-3.3_SOT223; SOT-223-3_TabPin2

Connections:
+5V: C8.1, C9.1, C18.1, C20.1, D9.1 (K), D10.1 (K), D11.1 (K), D12.1 (K), D15.4 (VDD), D16.4 (VDD), J8.1, J9.5, J18.1, J18.2, L1.2, U1.4, U6.4, U8.4 (FB), U9.3 (VI)
+12V: C17.1, J4.1, J4.3, J4.5, J4.7, J19.1, J19.2, R40.1, U8.1 (IN)
GND: C1.1, C2.1, C3.2, C4.1, C5.2, C6.1, C7.2, C8.2, C9.2, C10.1, C11.2, C12.1, C13.2, C14.2, C15.2, C16.2, C17.2, C18.2, C19.2, C20.2, C21.2, D1.2 (A), D2.2 (A), D4.2 (A), D5.2 (A), D6.2 (A), D7.1 (A1), D13.2 (A), D14.1 (A1), D15.1 (VSS), D16.1 (VSS), D17.2 (A), D20.1 (A1), D21.2 (A), D24.1 (A1), H1.1, H2.1, H3.1, H4.1, J1.3, J2.3, J3.2, J5.1, J5.3, J5.5, J5.7, J6.3, J7.2, J8.5, J9.3, J13.2, J14.5, J15.2, J16.1, J16.2, R3.1, R7.1, R12.1, R17.1, R20.2, R21.1, R37.2, R39.1, R43.1, R47.2, RV1.3, RV1.3a (3), RV1.3b (3), RV1.3c (3), RV1.3d (3), RV1.3e (3), RV2.3, RV2.3a (3), RV2.3b (3), RV2.3c (3), RV2.3d (3), RV2.3e (3), U2.4 (V-), U3.6 (~INH), U3.7 (GND), U3.8 (GND), U4.8 (Vss), U4.19 (Vss), U5.8 (GND), U5.13 (~OUT_EN), U7.2 (GND), U8.3 (GND), U8.5 (SD), U9.1 (GND)
unnamed: D1.1 (K), R1.2, R2.1
unnamed: D2.1 (K), R5.2, R6.1
unnamed: D3.2 (A), R8.2, U1.2, U1.3, U1.6, U1.7
unnamed: D3.1 (K), D7.2 (A2), J3.1, R9.2, R13.2, R14.1
unnamed: D4.1 (K), R10.2, R11.1
unnamed: C5.1, D5.1 (K), R14.2, U2.5 (+)
unnamed: D6.1 (K), R15.2, R16.1
unnamed: D8.2 (A), R25.2, U6.2, U6.3, U6.6, U6.7
unnamed: D9.2 (A), R29.1
unnamed: D10.2 (A), R30.1
unnamed: D11.2 (A), R31.1
unnamed: D12.2 (A), R28.1
unnamed: C7.1, D13.1 (K), R32.2, R34.2, U2.3 (+)
unnamed: D8.1 (K), D14.2 (A2), J7.1, R26.2, R32.1, R33.2, R34.1
unnamed: D15.2 (DIN), D16.3 (DOUT)
unnamed: C10.2, D16.2 (DIN), R38.1
unnamed: D17.1 (K), R40.2, R41.1
unnamed: D18.2 (A), D19.2 (A), R46.2
unnamed: D18.1 (K), D20.2 (A2), J13.1
unnamed: D21.1 (K), L1.1, U8.2 (OUT)
unnamed: D22.2 (A), D23.2 (A), R48.2
unnamed: D22.1 (K), D24.2 (A2), J15.1
unnamed: J1.1, R4.2, U4.1 (~MCLR/RE3)
unnamed: J1.4, U4.28 (ICSPDAT/RB7)
unnamed: J1.5, U4.27 (ICSPCLK/RB6)
unnamed: J2.1, J2.2, R13.1, RV1.1, RV1.2
unnamed: J4.2, R15.1
unnamed: J4.4, R1.1
unnamed: J4.6, R5.1
unnamed: J4.8, R10.1
unnamed: J5.2, R22.2, U3.5 (Y5)
unnamed: J5.4, R23.2, U3.4 (Y7)
unnamed: J5.6, R24.2, U3.2 (Y6)
unnamed: J5.8, R27.2, U3.1 (Y4)
unnamed: J6.1, J6.2, R33.1, RV2.1, RV2.2
unnamed: J8.3, J9.1, U4.14 (SCL/SCK/RC3)
unnamed: J8.4, J9.2, U4.15 (SDA/SDI/RC4)
unnamed: C14.1, J11.1, J12.2, R44.1, U7.7 (CANH)
unnamed: J11.2, J11.3, R42.2
unnamed: C13.1, J12.1, R42.1, R45.1, U7.6 (CANL)
unnamed: J14.2, J14.4, J14.6, U7.8 (Rs)
unnamed: J14.3, R47.1
unnamed: R8.1, R9.1, U1.1
unnamed: R25.1, R26.1, U6.1
unnamed: R35.2, R36.1, R37.1, R39.2, U2.2 (-)
unnamed: R18.2, R19.1, R20.1, R21.2, U2.6 (-)
unnamed: U3.11 (A), U4.3 (RA1)
unnamed: U3.10 (B), U4.4 (RA2/Vref-)
unnamed: U3.9 (C), U4.5 (RA3/Vref+)
unnamed: U3.3 (COM), U4.10 (RA6)
unnamed: C1.2, R2.2, R3.2, U3.13 (Y0)
unnamed: C2.2, R6.2, R7.2, U3.14 (Y1)
unnamed: C4.2, R11.2, R12.2, U3.15 (Y2)
unnamed: C6.2, R16.2, R17.2, U3.12 (Y3)
unnamed: R38.2, U4.13 (CCP1/RC2)
unnamed: U4.21 (RB0), U5.10 (~RST)
unnamed: U4.22 (RB1), U5.11 (SHIFT_CLK)
unnamed: U4.23 (RB2), U5.12 (LATCH_CLK)
unnamed: U4.26 (RB5), U5.14 (A)
unnamed: R28.2, U5.15 (Q_{A})
unnamed: R31.2, U5.1 (Q_{B})
unnamed: R30.2, U5.2 (Q_{C})
unnamed: R29.2, U5.7 (Q_{H})
unnamed: C15.1, R44.2, R45.2, U7.5 (Vref)
VDD: C3.1, C11.1, C21.1, J1.2, J8.2, J9.6, J14.1, J17.1, J17.2, R4.1, R22.1, R23.1, R24.1, R27.1, R46.1, R48.1, U2.8 (V+), U3.16 (V_{CC}), U4.20 (Vdd), U5.16 (V_{CC}), U7.3 (VCC), U9.2 (VO)
can_rx: J10.1, U4.24 (RB3), U7.4 (R)
can_tx: J10.2, U4.25 (RB4), U7.1 (D)
fuel_tank: R35.1, R36.2, U2.1, U4.7 (RA5)
sensor1: C19.1, D23.1 (K), U4.18 (RC7)
sensor2: C16.1, D19.1 (K), U4.17 (RC6)
voltage: C12.2, R41.2, R43.2, U4.2 (RA0)
water_tank: R18.1, R19.2, U2.7, U4.6 (RA4)


Board: 2 copper layers, 125.0 x 82.5 mm, 128 parts (0 on the bottom side), 75 nets.

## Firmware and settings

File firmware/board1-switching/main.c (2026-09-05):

#include "adc.h"
#include "comm.h"
#include "config.h"
#include "controller.h"
#include "i2c.h"
#include "i2c_board.h"
#include "interrupt.h"
#include "libcomm.h"
#include "libcomm_interface.h"
#include "relay_mon.h"
#include "relay_out.h"
#include "sensors.h"
#include "task.h"

#include <xc.h>

#define _XTAL_FREQ 64000000UL

static TaskController ctrl;

static void tick_init(void);

static void init(void) {
    relay_out_init();
    relay_mon_init();
    i2c_pins_init();
    i2c_init(comm_address());
    comm_interface_init();

    task_controller_init(&ctrl);
    config_init(&ctrl);
    /* adc_init kicks off the first conversion; the AD ISR schedules
     * per-channel processors via run_in_main_loop, so the scheduler must
     * be live before we start sampling. */
    adc_init(&ctrl);
    comm_init();
    sensors_init(&ctrl);
    controller_init(&ctrl);

    tick_init();

    /* Interrupts enabled last. */
    interrupt_init();

    /* Only now is it safe to answer on the bus - see i2c_start(). */
    i2c_start();
}

/* TMR0 in 8-bit mode clocked from Fosc/4 with /128 prescaler gives
 * 16 MHz / 128 = 125 kHz (8 us per count). Match value 124 in TMR0H
 * yields a 1 ms period interrupt.
 *
 * ISR context. */
void __interrupt(low_priority, irq(TMR0), base(8)) TMR0_ISR(void) {
    PIR3bits.TMR0IF = 0;
    task_controller_tick(&ctrl);
}

static void tick_init(void) {
    T0CON0bits.EN = 0;
    /* Priority is owned by interrupt_init's IPR clear-and-promote step;
     * TMR0 ends up low-priority correctly there. */
    T0CON1bits.CS = 0b010;    // Fosc/4 -> 16 MHz
    T0CON1bits.CKPS = 0b0111; // 16 MHz / 128 -> 125 kHz
    PIR3bits.TMR0IF = 0;
    PIE3bits.TMR0IE = 1;
    TMR0L = 0;
    TMR0H = 124; // 124 cycles + 1 for trigger at 125 kHz => 1 kHz / 1ms
    T0CON0bits.EN = 1;
}

void main(void) {
    init();
    while (1) {
        i2c_poll();
        task_controller_poll(&ctrl);
    }
}

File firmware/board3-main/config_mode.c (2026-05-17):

#include "config_mode.h"

#include "config.h"
#include "controller.h"
#include "libcomm.h"
#include "rtc.h"
#include "task_ids.h"

#include <xc.h>

/* Switching-board config-protocol addresses for the level-meter wire
 * offsets. Mirrors board1-switching/config.h — kept local because main
 * does not link against the switching board's sources. */
#define SWITCHING_OFFSET_WATER 0x10
#define SWITCHING_OFFSET_FUEL 0x11

#define SAMPLE_MS 20u
#define STABLE_TICKS 3u /* ~60 ms debounce on the RA7 switch */

/* RA7 is pulled up via WPUA7; the switch closes to ground when active. */
#define PIN_ACTIVE() (PORTAbits.RA7 == 0)

/* Button indices on the left board used by the menu. The four logical
 * actions are encoded with disjoint high-nibble flags (0x10 vs 0x20) so
 * the per-screen switches can match all four cases without collision
 * even though every event comes from the same I2C side. */
#define BTN_UP 1u     /* L1 */
#define BTN_DOWN 2u   /* L2 */
#define BTN_SELECT 3u /* L3 — "enter" */
#define BTN_BACK 4u   /* L4 — "exit" */

#define SIDE_LEFT COMM_ADDRESS_BUTTON_BOARD_L
#define SIDE_RIGHT COMM_ADDRESS_BUTTON_BOARD_R

#define TIME_FIELD_HOUR 0u
#define TIME_FIELD_MINUTE 1u

static volatile uint8_t active;
static volatile uint8_t raw_last;
static volatile uint8_t raw_stable;
static volatile uint8_t stable_ticks;

static volatile uint8_t screen;       /* ConfigScreen */
static volatile uint8_t menu_cursor;  /* 0..CONFIG_MENU_COUNT-1 */
static volatile uint8_t nav_cursor;   /* 0..4 */
static volatile uint8_t working_mask; /* live nav-enabled mask */
static volatile uint8_t time_field;   /* 0=hour, 1=minute */
static volatile uint8_t working_hour;
static volatile uint8_t working_minute;
static volatile uint8_t offset_target; /* 0=water, 1=fuel */
static volatile uint8_t offset_value;
/* Set while a menu commit (set_time / config_write / config_read) is in
 * flight. Suppresses re-submission and (cosmetic) is queryable by the UI. */
static volatile uint8_t op_busy;

static void enter(void);
static void exit_config(void);
static void load_time(void);
static void enter_offset(uint8_t target);
static uint8_t offset_address(uint8_t target);
static void handle_menu(uint8_t btn);
static void handle_nav(uint8_t btn);
static void handle_time(uint8_t btn);
static void handle_offset(uint8_t btn);
static void sample_task(TaskId id, void* ctx);
static void on_set_time_done(uint8_t ok, void* ctx);
static void on_offset_read_done(uint8_t ok, uint8_t value, void* ctx);
static void on_offset_write_done(uint8_t ok, void* ctx);

void config_mode_init(TaskController* ctrl) {
    active = 0;
    screen = CONFIG_SCREEN_MENU;
    menu_cursor = 0;
    nav_cursor = 0;
    time_field = TIME_FIELD_HOUR;
    working_hour = 0;
    working_minute = 0;
    offset_target = 0;
    offset_value = 0;
    working_mask = config_get_nav_enabled_mask();
    raw_last = PIN_ACTIVE() ? 1 : 0;
    raw_stable = raw_last;
    stable_ticks = STABLE_TICKS;
    if (raw_stable) {
        enter();
    }
    task_controller_add(ctrl, TASK_CONFIG_MODE, SAMPLE_MS, sample_task, 0);
}

uint8_t config_mode_active(void) {
    return active;
}

uint8_t config_mode_screen(void) {
    return screen;
}

uint8_t config_mode_menu_cursor(void) {
    return menu_cursor;
}

uint8_t config_mode_nav_cursor(void) {
    return nav_cursor;
}

uint8_t config_mode_nav_working_mask(void) {
    return working_mask;
}

uint8_t config_mode_time_field(void) {
    return time_field;
}

uint8_t config_mode_time_hour(void) {
    return working_hour;
}

uint8_t config_mode_time_minute(void) {
    return working_minute;
}

uint8_t config_mode_offset_target(void) {
    return offset_target;
}

uint8_t config_mode_offset_value(void) {
    return offset_value;
}

/* Runs from the I2C rx ISR (via controller dispatch). Keep it brief. */
void config_mode_on_button_pressed(uint8_t side, uint8_t button_idx) {
    if (!active) {
        return;
    }
    /* Translate (side, button) into the four logical actions. Anything else
     * is ignored — the menu only listens to the four mapped buttons.
     * Up/Down get the 0x10 high-nibble flag; Select/Back get 0x20 so the
     * per-screen switch statements can match without collision. */
    uint8_t btn;
    if (side == SIDE_LEFT && (button_idx == BTN_UP || button_idx == BTN_DOWN)) {
        btn = (uint8_t)(button_idx | 0x10u);
    } else if (side == SIDE_LEFT && (button_idx == BTN_SELECT || button_idx == BTN_BACK)) {
        btn = (uint8_t)(button_idx | 0x20u);
    } else {
        return;
    }

    switch (screen) {
        case CONFIG_SCREEN_MENU:
            handle_menu(btn);
            break;
        case CONFIG_SCREEN_NAV:
            handle_nav(btn);
            break;
        case CONFIG_SCREEN_TIME:
            handle_time(btn);
            break;
        case CONFIG_SCREEN_OFFSET:
            handle_offset(btn);
            break;
        default:
            break;
    }
}
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

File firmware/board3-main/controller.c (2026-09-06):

#include "controller.h"

#include "button_fx.h"
#include "config.h"
#include "config_mode.h"
#include "libcomm.h"
#include "libcomm_interface.h"
#include "nav_lights.h"
#include "rtc.h"
#include "task.h"
#include "task_ids.h"

#include <xc.h>

/* ============================================================================
 * Relay assignment — bit position in the 16-bit relay word matches the
 * switching board's wiring (see board1-switching/readme.md "Protocol Bit"
 * column). Callers address via these macros so the layout can be tweaked
 * without touching action logic.
 * ============================================================================
 */

#define RELAY_MAIN 0 /* main contactor — engaged whenever power_on */
#define RELAY_INSTRUMENTS 1
#define RELAY_AUTOPILOT 2
#define RELAY_NAV_BOW 3
#define RELAY_NAV_STERN 4
#define RELAY_NAV_STEAMING 5
#define RELAY_NAV_ANCHORING 6
#define RELAY_NAV_TRICOLOR 7
#define RELAY_INVERTER 8
#define RELAY_WATER_PUMP 9
#define RELAY_FRIDGE 10
#define RELAY_DECK_LIGHTS 11
#define RELAY_CABIN_LIGHTS 12
#define RELAY_USB 13
#define RELAY_AUX_1 14
#define RELAY_AUX_2 15

/* Nav-light bits in the relay word — contiguous at 3..7. */
#define NAV_MASK_BITS                                                                                                  \
    ((uint16_t)((1u << RELAY_NAV_BOW) | (1u << RELAY_NAV_STERN) | (1u << RELAY_NAV_STEAMING) |                         \
                (1u << RELAY_NAV_ANCHORING) | (1u << RELAY_NAV_TRICOLOR)))

/* ============================================================================
 * Button → action mapping
 * ============================================================================
 */

typedef enum {
    ACTION_NONE = 0,
    ACTION_TOGGLE_POWER,
    ACTION_TOGGLE_RELAY,
    ACTION_TOGGLE_NAV_MODE,
} ActionKind;

typedef struct {
    uint8_t kind;
    uint8_t param;
} ButtonAction;

/* Left panel (COMM_ADDRESS_BUTTON_BOARD_L = 0x44), buttons 0..6. */
static const ButtonAction left_actions[7] = {
    {ACTION_TOGGLE_POWER, 0},
    {ACTION_TOGGLE_RELAY, RELAY_INSTRUMENTS},
    {ACTION_TOGGLE_RELAY, RELAY_AUTOPILOT},
    {ACTION_TOGGLE_NAV_MODE, NAV_MODE_STEAMING},
    {ACTION_TOGGLE_NAV_MODE, NAV_MODE_RUNNING},
    {ACTION_TOGGLE_NAV_MODE, NAV_MODE_ANCHORING},
    {ACTION_TOGGLE_RELAY, RELAY_INVERTER},
};

/* Right panel (COMM_ADDRESS_BUTTON_BOARD_R = 0x46), buttons 0..6. */
static const ButtonAction right_actions[7] = {
    {ACTION_TOGGLE_RELAY, RELAY_WATER_PUMP},  {ACTION_TOGGLE_RELAY, RELAY_FRIDGE},
    {ACTION_TOGGLE_RELAY, RELAY_DECK_LIGHTS}, {ACTION_TOGGLE_RELAY, RELAY_CABIN_LIGHTS},
    {ACTION_TOGGLE_RELAY, RELAY_USB},         {ACTION_TOGGLE_RELAY, RELAY_AUX_1},
    {ACTION_TOGGLE_RELAY, RELAY_AUX_2},
};

/* ============================================================================
 * Power state machine
 *
 * OFF      ─L0──→ PENDING(target=ON)  ─channel_changed confirms main on──→ ON
 *                                     ─timeout (~2 s)────────────────→ ERROR
 * ON       ─L0──→ PENDING(target=OFF) ─channel_changed confirms main off─→ OFF
 *                                     ─timeout──────────────────────→ ERROR
 * ERROR    ─L0────────────────────────→ OFF
 *          ─late channel_changed (target match)──→ ON / OFF
 *
 * In OFF / PENDING / ERROR the display is blank, the nav-light RGB ring is
 * dark, only L0 is acted on (other button presses ignored), and the
 * battery / level / sensor polls run at a much slower cadence so the
 * inspector still sees freshness on the bus.
 * ============================================================================
 */

typedef enum {
    PWR_OFF = 0,
    PWR_PENDING = 1,
    PWR_ON = 2,
    PWR_ERROR = 3,
} PowerState;

static volatile uint8_t power_state;
static volatile uint8_t power_target;        /* PWR_OFF / PWR_ON — meaningful in PENDING / ERROR */
static volatile uint16_t power_pending_ticks; /* counted in retry_task at RETRY_TICK_MS */

#define POWER_PENDING_TIMEOUT_TICKS (2000u / RETRY_TICK_MS) /* ~2 s */

static volatile uint8_t nav_mode; /* NavMode                     */
static volatile uint8_t nav_error;
static volatile uint16_t relay_intent;  /* user-facing: relays 5..15   */
static volatile uint16_t relay_target;  /* materialised after policy   */
static volatile uint16_t channel_state; /* from channel_changed pushes */
static volatile uint8_t sensor_state;
static volatile uint8_t relay_dirty; /* target diverged from bus    */
static volatile uint16_t battery_mv;
static volatile uint8_t levels[2];

/* Power-off snapshot kept in RAM only (per todo: no EEPROM persistence).
 * Captured on the active -> inactive transition and reapplied when power
 * returns so the user's prior selection of relays and nav mode survives
 * the power toggle without relying on flash wear or boot-time defaults. */
static uint16_t saved_relay_intent;
static uint8_t saved_nav_mode;

/* ============================================================================
 * Outbound retry queue
 *
 * Single-slot latest-wins for relay_state: if the target changes again before
 * the previous write landed, we just want to send the latest value. Collapse
 * reduces I2C traffic when a burst of button presses lands in one tick.
 * ============================================================================
 */

#define RETRY_TICK_MS 200u
#define POLL_TICK_MS 200u
#define POLL_TICK_SLOW_MS 5000u
/* RTC ticks once per second; polling at 250 ms keeps the displayed clock
 * within a quarter second of the chip without being wasteful. */
#define RTC_TICK_MS 250u

/* Mask + expected value of the relay bits an action touched. button_fx uses
 * this to decide what to wait for before the press completes. */
typedef struct {
    uint16_t mask;
    uint16_t value;
} ActionEffect;

static void retry_task(TaskId id, void* ctx);
static void poll_battery_task(TaskId id, void* ctx);
static void poll_levels_task(TaskId id, void* ctx);
static void poll_sensors_task(TaskId id, void* ctx);
static void poll_channels_task(TaskId id, void* ctx);
static void poll_rtc_task(TaskId id, void* ctx);
static void on_rtc_read_done(uint8_t ok, const RtcTime* t, void* ctx);
static ActionEffect apply_action(const ButtonAction* a);
static void recompute_target(void);
static void apply_channel_observation(uint16_t curr_c);

static volatile RtcTime rtc_shadow;
static volatile uint8_t rtc_valid;

static volatile uint8_t relay_inflight;
static volatile uint8_t rtc_inflight;
static volatile uint16_t relay_inflight_value;

/* Staleness counters: incremented each poll tick (POLL_TICK_MS), reset
 * to 0 on successful response.  When the counter exceeds the threshold
 * the UI should show "error" instead of the stale value. */
#define STALE_THRESHOLD (10000u / POLL_TICK_MS) /* 10 s */

static volatile uint16_t batt_age;
static volatile uint16_t levels_age;
static volatile uint16_t sensors_age;
static volatile uint16_t channels_age;
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

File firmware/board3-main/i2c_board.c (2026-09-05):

#include "i2c_board.h"

#include "i2c.h"
#include "libcomm.h"

#include <xc.h>

void i2c_pins_init(void) {
    LATBbits.LATB1 = 1;
    LATBbits.LATB2 = 1;
    ANSELBbits.ANSELB1 = 0;
    ANSELBbits.ANSELB2 = 0;
    TRISBbits.TRISB1 = 0;
    TRISBbits.TRISB2 = 0;
    ODCONBbits.ODCB1 = 1;
    ODCONBbits.ODCB2 = 1;
    RB1I2Cbits.TH = 0b01;
    RB2I2Cbits.TH = 0b01;
#if I2C_FME
    RB1I2Cbits.PU = 0b11;
    RB2I2Cbits.PU = 0b11;
    SLRCONBbits.SLRB1 = 0;
    SLRCONBbits.SLRB2 = 0;
    RB1I2Cbits.SLEW = 0b00;
    RB2I2Cbits.SLEW = 0b00;
#else
    RB1I2Cbits.PU = 0b10;
    RB2I2Cbits.PU = 0b10;
    RB1I2Cbits.SLEW = 0b01;
    RB2I2Cbits.SLEW = 0b01;
#endif

    I2C1SCLPPS = 0x0A; /* RB2 -> SCL1 */
    RB2PPS = 0x37;
    I2C1SDAPPS = 0x09; /* RB1 -> SDA1 */
    RB1PPS = 0x38;
}

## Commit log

2026-02-09 Rearranged project
    [board1-switching.kicad_pcb, board1-switching.kicad_sch, board2-buttons.kicad_pcb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]
2026-02-10 Finished switching board
    [board1-switching.kicad_pcb, board1-switching.kicad_sch, psu.kicad_sch]
2026-02-10 Finished schematic for main board
    [board3-main.kicad_pcb, board3-main.kicad_sch]
2026-02-10 Changed signal connector to 6 pos
    [board1-switching.kicad_pcb, board1-switching.kicad_sch]
2026-02-11 Prepared buttons board
    [board2-buttons.kicad_pcb, board2-buttons.kicad_sch]
2026-02-11 Changed footprint of programming connector to smd 2mm
    [board1-switching.kicad_pcb, board1-switching.kicad_sch, board2-buttons.kicad_pcb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]
2026-02-11 Changed jumper connector to 2mm SMD
    [board3-main.kicad_pcb, board3-main.kicad_sch]
2026-02-11 Routed bilge pump through IC Added shore power and AC power signals
    [board1-switching.kicad_pcb, board1-switching.kicad_sch, board3-main.kicad_pcb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]
2026-02-12 Adjusted switching board connection order
    [board1-switching.kicad_pcb, board1-switching.kicad_sch]
2026-02-12 Added 3d model for terminal block
    [board1-switching.kicad_pcb, board1-switching.kicad_sch]
2026-02-12 Updated footprints
    [board1-switching.kicad_pcb, board1-switching.kicad_sch, board2-buttons.kicad_pcb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]
2026-02-17 Switched to 3.3V Added ESD protection Added display
    [board1-switching.kicad_pcb, board1-switching.kicad_sch, board2-buttons.kicad_pcb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]
2026-02-18 Added ESD and footprints
    [board1-switching.kicad_pcb, board1-switching.kicad_sch]
2026-02-18 Updated buttons layout
    [board2-buttons.kicad_pcb, board2-buttons.kicad_sch, board3-main.kicad_sch]
2026-02-19 Added ESD protection for other inputs Updated footprints
    [board1-switching.kicad_pcb, board1-switching.kicad_sch, board3-main.kicad_pcb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]
2026-02-19 Routed most of board 1
    [board1-switching.kicad_pcb, board1-switching.kicad_sch]
2026-02-22 Finished initail preparation of board 2
    [board2-buttons.kicad_pcb, board2-buttons.kicad_sch, board2-buttons.step]
2026-02-23 Finished initail preparation of board 1
    [board1-switching.kicad_pcb, board1-switching.kicad_sch]
2026-02-23 Increased width of the board by 2mm to simplify manufacturing
    [board2-buttons.kicad_pcb]
2026-02-24 Fixed footprints and clearances
    [board1-switching.kicad_pcb]
2026-02-25 Rerouted thinner traces
    [board1-switching.kicad_pcb]
2026-02-25 Min thickness 0.2
    [board1-switching.kicad_pcb]
2026-02-26 Moved op amps to board 1
    [board1-switching.kicad_pcb, board1-switching.kicad_sch, board3-main.kicad_pcb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]
2026-02-28 Fixed signal measurment
    [board1-switching.kicad_pcb, board1-switching.kicad_sch, meters.kicad_sch]
2026-02-28 Added decoupling capacitors
    [board2-buttons.kicad_pcb, board2-buttons.kicad_sch, board3-main.kicad_pcb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]
2026-02-28 Added missing 3d models
    [BladeFuseHolder.step, ButtonSMT_CnK_KSC2_J.step, CR2032-Keystone-1058.step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]
2026-03-01 Changed button Added led pipes Removed diodes
    [Button-EVPCD.step, board1-switching.kicad_pcb, board1-switching.kicad_sch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]
2026-03-02 Added prototype board
    [board0.kicad_pcb, board0.kicad_sch, board2-buttons.kicad_pcb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]
2026-03-02 Added stencil index hole
    [board0.kicad_pcb, board2-buttons.kicad_pcb]
2026-03-03 Added new ledpipe
    [Ledpipe-5x5.step, board3-main.kicad_pcb, board3-main.kicad_sch]
2026-03-06 Routed board 3
    [board3-main.kicad_pcb, board3-main.kicad_sch, display_ssd1322.kicad_sch]
2026-03-08 Routed boards 1 and 3
    [board1-switching.kicad_pcb, board1-switching.kicad_sch, board3-main.kicad_pcb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]
2026-04-06 Added pull up for I2C Refined the analog scheme Added DNP backup elements Added level shift for LEDs
    [board0.kicad_sch, board1-switching.kicad_pcb, board1-switching.kicad_sch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]
2026-04-06 Turned power sybmols
    [display_ssd1322.kicad_sch]
2026-04-07 Fixed display layout
    [board3-main.kicad_pcb, board3-main.kicad_sch, display_ssd1322.kicad_sch]
2026-04-07 Fixed main board layout
    [board3-main.kicad_pcb]
2026-04-08 Added mounting holes for board 1
    [board1-switching.kicad_sch, board2-buttons.step, board3-main.kicad_pcb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]
2026-04-09 Added vias to main board
2026-04-09 Prepared export
    [board2-buttons.kicad_pcb, board3-main.kicad_pcb]
2026-04-09 Fixed warnings for manufacturing
    [board2-buttons.kicad_pcb, board3-main.kicad_pcb]
2026-04-10 Removed solder paste from mounting holes for screen
    [board3-main.kicad_pcb]
2026-04-14 Added user marking on PCB for screen
    [board3-main.kicad_pcb]
2026-04-14 Created build scripts Added board2 firmware
2026-04-16 Fixed PCB resistor reference
    [board2-buttons.kicad_pcb]
2026-04-17 Added button effect controller
2026-04-18 Fixed warnings Fixed timer interval
    [input.c, interrupt.c, main.c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]
2026-04-18 Added oval mounting hole Fixed button indexing
    [board2-buttons.kicad_pcb, board2-buttons.kicad_sch]
2026-04-18 Added led effects
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2026-04-19 Added readme for the new boards
2026-04-19 Generated firmware for board 3
2026-04-19 Generated code for board1 switching
2026-04-19 Not allowing short if statements
    [comm.c, controller.c, display.c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]
2026-04-19 Added connection diagram for the panel
    [connection.kicad_pcb, connection.kicad_sch]
2026-04-20 Updated connection diagram
    [connection.kicad_sch]
2026-04-21 Fixed minor issues in Board 1
    [board1-switching.kicad_sch]
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2026-04-24 Fixed I2C timing on main board Moved control buttons to left panel Button message now sends more data in fewer bytes
    [comm.c, config_mode.c, controller.c]
2026-04-24 Fixed I2C timing Added recovery from RTC error
    [comm.c]
2026-04-25 minor tweaks to board 2 pcb
    [board2-buttons.kicad_pcb, board2-buttons.kicad_sch]
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2026-04-26 Moved i2c to central library
2026-04-26 Moved board3 to new api
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2026-04-30 Enabled interrupts Trying to fix dependency change deteciton while building
    [interrupt.c]
2026-04-30 Switching modes between client and host
2026-05-01 DMA TX channel is now armed after start
2026-05-01 Added missing event handlers Moved button code to use i2c from libcomm
    [comm.c, i2c_board.c, main.c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]
2026-05-02 Migrated board1 to libcomm
2026-05-03 Fixed ADC for board 1
    [adc.c, controller.c, i2c_board.c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]
2026-05-03 Another refactor of i2c
2026-05-08 Fixed I2C some state transitions
2026-05-09 put back the dma priority
2026-05-10 reverted wrong code disarming DMA with event
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2026-05-10 Fixed reboot loop error
    [i2c_log.c]
2026-05-10 Updated board state on/off
2026-05-17 Added calibration of ADC
2026-05-18 Added error display when floats are not connected
    [adc.c]
2026-05-18 Moved ADC to low priority on switching board No success rate is 99% on 100kHz
2026-05-18 Low priority interrupts for remaining boards
2026-05-18 Fixed relay indexing
2026-05-18 Enabled fast mode for i2c
2026-05-18 Fixed i2c communication errors
    [i2c_board.c]
2026-09-05 Working CLI flash path, a debug build, and the I2C boot-window fix
    Ported from the i2c-redesign investigation. Only the parts that apply to
    main are here: everything else fixed there was specific to files the
    redesign rewrote (its controller.c, the (kind, result) log split, the
    EEPROM brightness field, the host test suite), none of which exist on this
    branch.
    flash.sh did not work. Three things were wrong:
    device 18F27Q84 -> 18F57Q84 the DFP ships programming scripts for
    pic18f57q84 only; selecting the real part
    fails with "No tool device file" and the
    tool never initialises
    tool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
    [main.c]
2026-09-05 WIP: port the interrupt-driven I2C driver from i2c-redesign
    Brings libcomm's driver, protocol layer and the three boards' API
    adaptation across from i2c-redesign, plus four fixes found on the bench.
    Deliberately excludes that branch's unrelated board-3 work (controller
    rewrite, config-mode/display/indicator changes, RTC removal) and its
    bench instrumentation.
    Fixes on top of the ported tip, in decreasing order of evidence:
    1. g_q_active — separate in-flight task cursor. prepend_completed_task
    injects an inbound client message ahead of g_q_head from ISR context,
    so the ISRs servicing a host transaction wrote their completion into
    the inbound message's slot and zeroed rx_got; i2c_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
    [comm.c, controller.c, display.c]
2026-09-05 i2c: drain the RX buffer at Stop; order terminating events before ADRIF
    Two further driver fixes on top of the port, plus removal of the
    temporary diagnostics from d27b7e7 (the wire-log overlay is still on,
    see below).
    1. drain_rx() in isr_on_stop's FSM_HOST_RX branch. The final byte's
    RXIF and the transaction's PCIF can be pending together, and all four
    I2C vectors share one priority level, so hardware vector order — not
    arrival order — decides which runs first. When Stop won, finish()
    captured rx_got before the last byte was read out of RXB. On a framed
    response that byte is the CRC, so the loss fails validation rather
    than truncating data. Real race; not the cause o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
    [comm.c, controller.c, main.c]
2026-09-05 i2c: fix the write->read turnaround; add a logic-analyser sniffer
    The host read phase never reached the bus. Every poll went out as
    "Start, addr W, data, ACK, Stop" with no repeated start, so the read
    returned zero bytes and still completed as OK — battery, levels, sensors
    and channel_state all read as 0 on the main board, and button_fx timed
    out red waiting for a channel_state confirmation that could not arrive.
    Cause: isr_on_count_zero cleared RSEN *before* setting S. RSEN is what
    makes the hardware hold MDR and emit a Restart instead of a Stop, so
    clearing it retired the pending Restart and the write phase terminated in
    a Stop. Setting S afterwards did nothing useful.
    Fix: leave RS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
2026-09-06 button_fx: stop the spurious and stuck red states; confirm power actively
    Three defects made the button LEDs contradict what the panel was doing.
    All are in the press/converge state machine, not the rendering.
    * TIMEOUT_MS was 100 ms, shorter than the 200 ms channel_state poll it
    waits on. A press that was working perfectly still timed out to
    FX_ERROR, so the power button flashed red for no reason.
    * button_fx_on_channel_state only converged FX_PENDING slots. Once a
    slot reached FX_ERROR nothing could clear it except pressing that
    button again, so a channel that had since reached the requested
    state kept flashing red indefinitely.
    * Switching a channel off still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
    [controller.c]
2026-09-06 button_fx: track every button's channel continuously; compound nav buttons
    Button feedback was only ever set by the press that caused it, so an
    untouched button could not show a fault and the three nav buttons had no
    relationship to the lights they select. Feedback now derives from the
    commanded relay target, refreshed every tick.
    controller_button_channel_mask() gives the channel mask a button's light
    tracks, derived from the same action tables the press dispatch uses so the
    mapping is not duplicated. The nav buttons are compound: each reports the
    whole nav-light group, but only while its own mode is selected. An
    unselected nav button reports mask 0 — dark, and never an error — while
    t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
    [controller.c]
2026-09-06 config: serve config_read on the main board; record why the RTC stays off
    comm_on_config_read_requested was an empty stub on board 3, so it never
    staged a response and every config_read addressed to the main board came
    back empty — its nav-enabled mask and even the universal device-id and
    revision bytes were unreadable over the bus, while boards 1 and 2 served
    theirs. Implemented the same way they do.
    Verified over the bus with tools/inspector:
    board 1 0x00 device_id 0x42, 0x10 water 100, 0x11 fuel 100,
    0x12 battery 120, 0x13 level_mode 0x05 (both meters 0-190R)
    board 3 0x00 device_id 0x40, 0x01/0x02 revisions, 0x10 nav mask 0x1F
    (all four previously fail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
    [comm.c, controller.c]
2026-09-06 rtc: poll the DS3231 from main's loop, so the clock actually runs
    The RTC was disabled in a WIP commit and stayed that way because
    re-enabling it reset the board within a few button presses. The hardware
    was never at fault: the DS3231 is fitted and answers correctly.
    The cause is hardware stack depth, and this time with unambiguous
    evidence rather than a sticky flag. Clearing PCON0 to 0x3F before a run
    and reading it back after the fault gave 0xBF -- bit 7 STKOVF set, a
    genuine overflow. (An earlier reading of the same bit was worthless:
    nothing clears it, so it had been set hours before by something else.)
    XC8 measures main at 22 of the PIC18's 31 hardware stack levels, and all
    of that de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
    [controller.c, main.c]
2026-09-06 Revert "rtc: poll the DS3231 from main's loop, so the clock actually runs"
    This reverts commit 1bb4951. The board still resets on the first power
    press with it applied, so the clock is not worth a panel that restarts.
    My verification of 1bb4951 was inadequate and the claim in its message
    that the board "stays alive through five button presses" is wrong. I
    checked only that the bus still carried traffic — but a board that has
    just reset carries exactly the same traffic, because it comes straight
    back up and resumes polling. Confirming "alive" proves nothing about
    whether a reset happened.
    The reset is unmistakable on the analyser once you know the signature:
    main button_changed W[02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
    [controller.c, main.c]
2026-09-06 button_fx: flag a channel that loses voltage after it has settled
    A button that had converged to FX_IDLE never re-examined itself, so a
    channel that dropped out later — a blown fuse, a lost supply — kept
    showing solid white as though nothing had happened. Only FX_PENDING and
    FX_ERROR slots were reconciled against the bus.
    button_fx_on_channel_state now evaluates every mapped slot each time an
    observation arrives. A settled slot whose channel stops matching goes to
    FX_ERROR and renders flashing red, which is the same fault as a press
    that never took effect and reads the same way to the user.
    The transition is asserted only when the channel was asked to be on. The
    inverse — commanded o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
